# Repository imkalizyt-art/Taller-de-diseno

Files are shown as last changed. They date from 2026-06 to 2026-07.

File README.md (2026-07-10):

# Taller-de-diseno

Sistema IoT que monitorea la humedad del suelo y alerta a un jardinero mediante Telegram. Las mediciones se envían a un dashboard web personalizado alojado en Railway y se almacenan en una base de datos PostgreSQL de Aiven. El sistema también utiliza OpenWeatherMap para consultar el pronóstico de lluvia y mantiene ThingSpeak como respaldo del historial.

**Integrantes:** Enzo Quiñones, Agustín Lastra, Matías Pineda, Carlos León  
**Ramo:** Taller de Diseño en Ingeniería — TEI 201  
**Profesor:** Sebastián Duarte  

## ¿Qué hace el sistema?

**Problema que resuelve:** permite conocer la humedad real del suelo y entregar información útil para decidir cuándo regar, evitando depender solamente de la observación visual o de horarios fijos.

1. El sensor capacitivo mide la humedad del suelo cada 30 segundos.
2. El ESP8266 convierte la lectura ADC en un porcentaje de humedad.
3. Si la humedad cae bajo el 35 %, el suelo se considera seco.
4. Cada medición se envía al dashboard personalizado mediante una API alojada en Railway.
5. Railway guarda los datos en una base PostgreSQL de Aiven para mantener un historial.
6. El dashboard muestra la humedad actual, el valor ADC, el estado del suelo, estadísticas y un gráfico histórico.
7. Cuando el suelo está seco, el ESP8266 envía una alerta por Telegram al jardinero.
8. El mensaje incluye el porcentaje de humedad, el valor ADC, la hora, la temperatura, el pronóstico de lluvia y un enlace al dashboard.
9. Si el suelo continúa seco, se envía un recordatorio cada 10 minutos.
10. Cuando el suelo vuelve a estar húmedo, se envía una confirmación por Telegram.
11. ThingSpeak se mantiene como respaldo secundario de las mediciones.

## Hardware utilizado

| Componente | Modelo |
|---|---|
| Microcontrolador | ESP8266 NodeMCU V3 (ESP-12E, CP2102) |
| Sensor de humedad | Capacitive Soil Moisture Sensor V1.2 |
| Módulo de carga | TP4056 con protección |
| Batería | Li-Po 3.7 V, 2000 mAh |
| Panel solar | 6 V, 1 W |
| Placa de pruebas | Protoboard |
| Indicador | LED conectado al pin D5 |

## Software y plataformas

| Herramienta | Uso |
|---|---|
| Arduino IDE | Desarrollo y carga del firmware |
| Railway | Hosting del backend y del dashboard personalizado |
| Aiven PostgreSQL | Almacenamiento persistente de las mediciones |
| Flask | Backend y API del dashboard |
| Chart.js | Gráfico histórico de humedad |
| Telegram Bot API | Envío de alertas al jardinero |
| OpenWeatherMap API | Pronóstico de lluvia |
| ThingSpeak | Respaldo secundario del historial |
| NTP | Fecha y hora utilizadas por el sistema |

Librerías principales del firmware: `ESP8266WiFi`, `ESP8266HTTPClient`, `WiFiClientSecure`, `ThingSpeak`, `UniversalTelegramBot`, `ArduinoJson` y `NTPClient`.

Dependencias principales del dashboard: `Flask`, `gunicorn` y `psycopg`.

## Estructura del repositorio

```text
Taller-de-diseno/
├── dashboard/          # Página web, API y conexión con Aiven
├── firmware/           # Código fuente del ESP8266
├── hardware/           # Esquema de conexiones y lista de componentes
├── diseno-3d/          # Archivos de Fusion 360, planos y renders
├── docs/               # Documentación y evidencias
├── testing/            # Resultados y protocolo de pruebas
├── FUENTES.md          # Librerías, fuentes externas e IA utilizadas
└── README.md           # Descripción e instrucciones del proyecto
```

## Cómo configurar el proyecto

### 1. Instalar librerías en Arduino IDE

Ir a **Herramientas → Administrar bibliotecas** e instalar:

- `ThingSpeak` de MathWorks.
- `UniversalTelegramBot` de Brian Lough.
- `ArduinoJson` de Benoit Blanchon.
- `NTPClient` de Fabrice Weinberg.

Las librerías `ESP8266WiFi`, `ESP8266HTTPClient` y `WiFiClientSecure` se incluyen con el paquete de placas ESP8266.

### 2. Configurar credenciales en el firmware

En el archivo del firmware deben completarse las siguientes variables:

```cpp
const char* WIFI_SSID = "TU_RED_WIFI";
const char* WIFI_PASSWORD = "TU_CONTRASENA_WIFI";

const char* TELEGRAM_TOKEN = "TU_TOKEN_TELEGRAM";
const char* TELEGRAM_CHAT_ID = "TU_CHAT_ID";

unsigned long TS_CHANNEL_ID = TU_CHANNEL_ID;
const char* TS_WRITE_KEY = "TU_API_KEY_THINGSPEAK";

const char* OWM_API_KEY = "TU_API_KEY_OPENWEATHERMAP";

const char* DEVICE_API_KEY = "TU_DEVICE_API_KEY_DE_RAILWAY";
```

La clave `DEVICE_API_KEY` debe ser exactamente igual a la variable configurada en Railway. Las credenciales reales no deben subirse al repositorio público.

El firmware envía las mediciones a:

```text
https://taller-de-diseno-production.up.railway.app/api/mediciones
```

### 3. Configurar el dashboard

El dashboard se encuentra en la carpeta `dashboard/`.

En Railway se deben configurar estas variables:

```text
DATABASE_URL
DEVICE_API_KEY
HUMIDITY_THRESHOLD=35
ONLINE_WINDOW_MINUTES=15
```

- `DATABASE_URL` corresponde a la URI privada entregada por Aiven.
- `DEVICE_API_KEY` debe coincidir con la clave escrita en el firmware.
- El directorio raíz del servicio en Railway debe ser `/dashboard`.

Dashboard público:

**https://taller-de-diseno-production.up.railway.app**

### 4. Cargar el firmware

1. Conectar el NodeMCU V3 mediante USB.
2. Seleccionar la placa **NodeMCU 1.0 (ESP-12E Module)**.
3. Seleccionar el puerto correspondiente al conversor CP2102.
4. Verificar y cargar el código.
5. Abrir el Monitor Serial a 115200 baudios.
6. Comprobar que aparezcan las lecturas del sensor y el mensaje de envío correcto al dashboard.
7. Abrir el dashboard y verificar que la medición nueva aparezca en la página.

## Calibración del sensor

El sensor capacitivo entrega una lectura inversa a la humedad:

- Un valor ADC mayor representa un suelo más seco.
- Un valor ADC menor representa un suelo más húmedo.

La configuración actual es:

```cpp
const int SENSOR_SECO = 850;
const int SENSOR_AGUA = 380;
const int UMBRAL_RIEGO = 35;
```

La conversión se realiza mediante interpolación lineal:

- `SENSOR_SECO = 850` corresponde a 0 % de humedad.
- `SENSOR_AGUA = 380` corresponde a 100 % de humedad.
- Bajo 35 %, el sistema considera que el suelo necesita riego.

Para recalibrar el sensor se debe medir el valor ADC al aire y luego con la zona sensible en agua, reemplazando los valores anteriores por los resultados obtenidos.

## Dashboard personalizado

El dashboard fue desarrollado por el equipo y es la interfaz principal del sistema:

**https://taller-de-diseno-production.up.railway.app**

La página muestra:

- Humedad actual del suelo.
- Valor ADC.
- Estado seco o humedad adecuada.
- Recomendación de riego.
- Fecha y hora de la última medición.
- Promedio, mínimo y máximo de las últimas 24 horas.
- Cantidad de mediciones registradas.
- Gráfico histórico de humedad.
- Línea de referencia del umbral del 35 %.
- Estado de conexión del ESP8266.

El flujo principal de datos es:

```text
Sensor capacitivo → ESP8266 → API en Railway → PostgreSQL en Aiven → Dashboard personalizado
```

ThingSpeak no se utiliza como dashboard principal; se conserva únicamente como respaldo secundario del historial.

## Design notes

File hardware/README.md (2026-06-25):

# Lista de Materiales y Costos — Hardware

**Proyecto:** Sistema IoT de Monitoreo de Humedad del Suelo  
**Ramo:** TEI 201 — Taller de Diseño en Ingeniería  
**Integrantes:** Enzo Quiñones, Agustín Lastra, Matías Pineda, Carlos León

---

## Lista de Componentes

| N° | Componente | Modelo / Especificación | Cantidad | Precio unit. (CLP) | Total (CLP) | Fuente de referencia |
| 1 | Microcontrolador WiFi | ESP8266 NodeMCU V3 (ESP-12E, CP2102) | 1 | $5.090 | $5.090 | mechatronicstore.cl |
| 2 | Sensor de humedad del suelo | Capacitive Soil Moisture Sensor V1.2 | 1 | $2.990 | $2.990 | maxelectronica.cl |
| 3 | Módulo elevador de voltaje | XL6009 DC-DC Step-Up Boost Converter | 1 | $2.490 | $2.490 | maxelectronica.cl |
| 4 | Módulo cargador de batería | TP4056 con protección integrada (USB-C) | 1 | $2.490 | $2.490 | maxelectronica.cl |
| 5 | Batería recargable | Li-Po 3.7V 2000mAh modelo 103450 | 1 | $5.990 | $5.990 | makerschile.cl (ref.) |
| 6 | Panel solar | 6V 1W (policristalino) | 1 | $3.490 | $3.490 | mechatronicstore.cl (ref.) |
| 7 | Placa de pruebas | Protoboard 830 puntos | 1 | $2.490 | $2.490 | maxelectronica.cl |
| 8 | Cables de conexión | Jumper macho-macho / macho-hembra (x40) | 1 pack | $1.990 | $1.990 | mechatronicstore.cl |

**Costo total del prototipo: $27.020 CLP**

## Justificación de Componentes

### 1. ESP8266 NodeMCU V3 (ESP-12E, CP2102)

El ESP8266 fue elegido como cerebro del sistema por tres razones principales:

- **WiFi integrado:** a diferencia de un Arduino UNO que requeriría un módulo WiFi externo adicional, el ESP8266 integra conectividad WiFi 802.11 b/g/n en el mismo chip, reduciendo componentes y costos.
- **Suficiente capacidad para el proyecto:** con 80 MHz de procesador, 4 MB de memoria flash y 1 pin ADC de 10 bits (0–1023), cubre exactamente las necesidades del sistema: leer el sensor analógico, hacer solicitudes HTTP a OpenWeatherMap y ThingSpeak, y enviar mensajes por Telegram.
- **Compatibilidad directa:** el sensor capacitivo V1.2 opera a 3.3V–5V, compatible con los GPIOs del NodeMCU sin necesidad de adaptadores de nivel.

### 2. Capacitive Soil Moisture Sensor V1.2

El sensor capacitivo fue elegido por sobre el sensor resistivo (tipo FC-28) por razones técnicas y de durabilidad:

- **Principio capacitivo vs. resistivo:** el sensor resistivo hace pasar corriente por el suelo entre dos electrodos metálicos, lo que provoca electrólisis y corrosión en pocas semanas. El sensor capacitivo mide el cambio en la constante dieléctrica del suelo sin contacto eléctrico directo, eliminando este problema.
- **Mayor vida útil:** el fabricante especifica una vida útil mínima de 3 años, adecuada para un sistema de monitoreo permanente en jardín.
- **Salida analógica directa:** entrega una señal analógica de 0–3V proporcional a la humedad, compatible con el único pin ADC del ESP8266 (A0). No requiere conversión adicional.
- **Recubrimiento anticorrosión:** el electrodo tiene una capa protectora que lo hace apto para estar enterrado permanentemente en tierra húmeda.
- **Compatibilidad de voltaje:** opera entre 3.3V y 5.5V, compatible directamente con la salida del ESP8266.

---

### 3. XL6009 DC-DC Step-Up Boost Converter

El módulo XL6009 se incorporó para resolver un problema de voltaje en el sistema de alimentación:

- **Problema:** la batería Li-Po entrega 3.7V nominales (3.2V–4.2V según su estado de carga). El ESP8266 requiere 5V en su pin VIN para operar correctamente a través de su regulador interno de 3.3V.
- **Solución:** el XL6009 eleva el voltaje de la batería (3.2V–4.2V) a un voltaje de salida estable de 5V, garantizando operación continua del ESP8266 independientemente del nivel de carga de la batería.
- **Por qué XL6009 y no LM2596:** el LM2596 es un convertidor reductor (buck), no elevador. El XL6009 es específicamente un elevador de voltaje (boost), necesario para subir de 3.7V a 5V.
- **Eficiencia:** con una eficiencia de conversión de hasta 94%, minimiza las pérdidas energéticas, lo cual es importante para prolongar la autonomía con batería solar.

---

### 4. TP4056 con Protección Integrada

El módulo TP4056 gestiona la carga segura de la batería Li-Po desde el panel solar:

- **Protección contra sobrecargas:** el chip TP4056 controla el proceso de carga mediante el método CC/CV (corriente constante / voltaje constante), cortando la carga cuando la batería alcanza 4.2V para prevenir daños.
- **Protección integrada:** se eligió la versión con DW01A + FS8205A (protección adicional), que añade protección contra sobredescarga, sobrecorriente y cortocircuito — esencial para un sistema autónomo sin supervisión constante.
- **Por qué no conectar el panel solar directo a la batería:** un panel solar sin regulación puede sobrecargar la batería Li-Po con voltajes superiores a 4.2V, lo que genera riesgo de hinchamiento, daño permanente o incendio.
- **Compatibilidad:** acepta entrada de 4.5V–5.5V, compatible con el panel solar de 6V (que en condiciones normales entrega ~5V bajo carga).

---

### 5. Batería Li-Po 3.7V 2000mAh (modelo 103450)

- **Capacidad elegida:** 2000mAh permite autonomía estimada de 8–12 horas de operación continua del sistema, suficiente para días con poca luz solar (nublado) donde el panel no recarga completamente.
- **Química Li-Po vs. alcalina:** las baterías alcalinas (AA/AAA) no son recargables por panel solar. El Li-Po permite ciclos continuos de carga/descarga sin efecto memoria y entrega alta densidad de energía en formato compacto.
- **Voltaje nominal 3.7V:** compatible con el módulo TP4056 (diseñado para celdas Li-Po de una celda a 3.7V) y con el XL6009 (rango de entrada mínimo 3.5V).
- **Formato físico:** el modelo 103450 (10mm × 34mm × 50mm) es compacto y fácil de integrar en el protoboard o carcasa del prototipo.

---

### 6. Panel Solar 6V 1W

- **Fuente de energía renovable:** permite que el sistema opere de forma autónoma en un jardín sin acceso a red eléctrica, cumpliendo con el requisito de instalación permanente.
- **Potencia elegida (1W / ~166mA a 6V):** el ESP8266 consume aproximadamente 80mA en operación WiFi. Con 5–6 horas de sol útil diario, el panel entrega energía suficiente para recargar la batería y compensar el consumo del sistema.
- **Voltaje de 6V:** entrega ~5V bajo carga, compatible con el rango de entrada del TP4056 (4.5V–5.5V). No se conecta directamente a la batería — siempre pasa por el TP4056.
- **Formato pequeño:** un panel de 1W es compacto y discreto para instalación en jardín, sin requerir estructura de soporte especial.

---

### 7. Protoboard 830 puntos

- **Prototipado sin soldadura:** permite modificar el circuito rápidamente durante el desarrollo, depuración y ajuste de parámetros (pines, resistencias, reordenamiento de componentes) sin necesidad de herramientas de soldadura.
- **Capacidad suficiente:** 830 puntos es el estándar para proyectos de complejidad media; permite ubicar el NodeMCU, el TP4056, el XL6009 y los cables del sensor con espacio disponible.
- **Etapa de prototipo:** para una versión final de producción, el circuito sería transferido a una PCB, pero en etapa de prototipo universitario la protoboard es la solución estándar.

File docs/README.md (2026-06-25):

# Manual de Uso — Sistema de Riego Inteligente IoT

**Proyecto:** Sistema IoT de monitoreo de humedad del suelo  
**Ramo:** TEI 201 — Taller de Diseño en Ingeniería  
**Integrantes:** Enzo Quiñones, Agustín Lastra, Matías Pineda, Carlos León

## 1. Descripción general

El sistema monitorea la humedad del suelo de forma autónoma mediante conexion a wifi, notifica al jardinero por Telegram cuando el suelo necesita riego. Funciona con batería recargable y panel solar, por lo que no requiere conexión a la red eléctrica.

## 2. Componentes del sistema

 Componente  Función 

- ESP8266 NodeMCU V3  Cerebro del sistema: lee el sensor, procesa datos y envía alertas 
- Sensor Capacitivo V1.2  Mide la humedad del suelo 
- Batería Li-Po 3.7V 2000mAh  Alimentación del sistema 
- Panel solar 6V 1W  Recarga la batería durante el día 
- Módulo TP4056  Controla la carga de la batería de forma segura 

## 3. Encendido del sistema

1. Asegurarse de que la batería esté cargada (el LED del TP4056 debe estar azul o verde)
2. Conectar la batería al módulo TP4056
3. El ESP8266 enciende automáticamente y se conecta al WiFi configurado
4. Esperar aproximadamente **10–15 segundos** para que establezca conexión
5. El sistema comienza a medir y enviar datos a ThingSpeak de inmediato

## 4. Mensajes de Telegram

El sistema envía tres tipos de mensajes automáticos:

### Alerta de suelo seco
- Se envía cuando la humedad baja del 35%.

🚨 ALERTA: Suelo seco detectado

- 💧 Humedad: 22%
- Valor ADC: 714
- 🕐 Hora: 14:32:05 UTC
- 🌧️ Pronóstico lluvia próximos 5 días: No se esperan lluvias
- ✅ Recomendación: Regar hoy
- Ver historial: https://thingspeak.mathworks.com/channels/3416600
###  Recordatorio periódico
- Si el suelo sigue seco después de 10 minutos, se envía un recordatorio con los datos actualizados.
### 🟢 Confirmación de suelo húmedo
Se envía automáticamente cuando la humedad vuelve a superar el 35% tras haber estado seca.
- Suelo húmedo — No se requiere riego

💧 Humedad actual: 61%
🕐 Hora: 15:10:22 UTC

## 5. Ver el historial de datos

1. Abrir el navegador e ir a:  
   👉 https://thingspeak.mathworks.com/channels/3416600
2. El dashboard muestra tres gráficos en tiempo real:
   - **Field 1:** Valor ADC crudo del sensor
   - **Field 2:** Porcentaje de humedad calculado
   - **Field 3:** Estado de alerta (0 = húmedo, 1 = seco)
3. Es posible filtrar por rango de fechas usando los controles del canal

---

## 6. Interpretación de la humedad

 Rango  Estado, Acción recomendada 

 - **0% – 35%**    Suelo seco  Regar — el sistema ya habrá alertado 
-  **35% – 60%**   Humedad moderada  Monitorear 
- **60% – 100%**   Suelo húmedo  No requiere riego 

## 7. Mantenimiento

### Revisión semanal
- Verificar que el panel solar esté expuesto al sol sin obstrucciones
- Revisar que el sensor esté correctamente insertado en el suelo (hasta la línea marcada, sin sumergir la electrónica)
- Confirmar que la conexion desde el dispostivo al celular esten funcionando de manera correcta

### Revisión mensual
- Revisar conexiones en el protoboard
- Verificar nivel de carga de la batería
- Limpiar el sensor o la parte que cubre el sensor con paño húmedo si hay acumulación de tierra

### Recalibración del sensor
Si las lecturas de humedad parecen incorrectas:
1. Medir el valor ADC con el sensor en aire → actualizar SENSOR_SECO
2. Medir el valor ADC con el sensor en agua → actualizar SENSOR_AGUA
3. Cargar el firmware actualizado al ESP8266

## 8. Solución de problemas

Síntoma  Causa probable  Solución 

- No llegan mensajes a Telegram  Sin conexión WiFi  
- Humedad siempre en 0% o 100%  Sensor descalibrado  Recalibrar con mediciones reales 
- El sistema no enciende  Batería descargada  Conectar al cargador o esperar carga solar 
- Mensajes repetidos muy seguidos  Bug en anti-spam  Revisar valor de millis() en el código 

## 9. Apagar el sistema

Desconectar la batería del módulo TP4056. El sistema no tiene interruptor físico; simplemente se desconecta la alimentación.

## 10. Contacto del equipo

Para dudas sobre el sistema, contactar a cualquier integrante del equipo a través del curso TEI 201.

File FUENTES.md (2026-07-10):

# FUENTES DEL PROYECTO

Este archivo registra las librerías, servicios, códigos externos adaptados y herramientas de inteligencia artificial utilizadas en el desarrollo del sistema de monitoreo de humedad del suelo.

---

## 1. Librerías utilizadas

| Librería, dependencia o servicio | Versión | Enlace oficial | Uso en el proyecto |
|---|---:|---|---|
| ESP8266 Arduino Core (`ESP8266WiFi`, `ESP8266HTTPClient`, `WiFiClient`, `WiFiClientSecure` y `WiFiUDP`) | 3.1.2 | https://github.com/esp8266/Arduino | Conexión Wi-Fi del NodeMCU, solicitudes HTTP/HTTPS, comunicación con el dashboard y conexión NTP |
| ThingSpeak | 2.0.0 | https://github.com/mathworks/thingspeak-arduino | Respaldo secundario de las mediciones de humedad, estado del suelo y lluvia pronosticada |
| UniversalTelegramBot | 1.3.0 | https://github.com/witnessmenow/Universal-Arduino-Telegram-Bot | Envío de alertas, recordatorios y confirmaciones de riego por Telegram |
| ArduinoJson | 6.21.5 | https://arduinojson.org | Lectura de respuestas de OpenWeatherMap y creación del JSON enviado a Railway |
| NTPClient | 3.2.1 | https://github.com/arduino-libraries/NTPClient | Obtención de fecha y hora para los mensajes del sistema |
| Flask | `>=3.0,<4` | https://flask.palletsprojects.com | Backend del dashboard, recepción de mediciones y creación de las rutas de la API |
| Psycopg | `>=3.1,<4` | https://www.psycopg.org/psycopg3/docs/ | Conexión entre la aplicación Flask y PostgreSQL de Aiven |
| Gunicorn | `>=22,<24` | https://gunicorn.org | Ejecución del backend Flask en Railway |
| Chart.js | 4.4.7 | https://www.chartjs.org/docs/latest/ | Gráfico histórico de humedad y línea del umbral de riego |
| Railway | Servicio web | https://docs.railway.com | Hosting del backend y del dashboard personalizado |
| Aiven for PostgreSQL | PostgreSQL 17 | https://aiven.io/docs/products/postgresql | Almacenamiento persistente del historial de mediciones |
| OpenWeatherMap | 5 Day / 3 Hour Forecast API | https://openweathermap.org/forecast5 | Consulta de temperatura y lluvia pronosticada |

---

## 2. Código externo adaptado

### Conexión Wi-Fi y solicitudes de red

- **Fuente:** documentación oficial de ESP8266 Arduino Core.  
  https://arduino-esp8266.readthedocs.io/en/latest/esp8266wifi/readme.html
- **Adaptación realizada:** se incorporó la conexión del NodeMCU a la red Wi-Fi, control del estado de conexión y uso de clientes HTTP y HTTPS para comunicarse con ThingSpeak, Telegram, OpenWeatherMap y Railway.

### Lectura y calibración del sensor capacitivo

- **Fuente:** documentación del Capacitive Soil Moisture Sensor V1.2.  
  https://www.sigmaelectronica.net/manuals/SMTMS-2-4.pdf
- **Adaptación realizada:** la lectura ADC se transforma en porcentaje mediante interpolación lineal entre `SENSOR_SECO = 850` y `SENSOR_AGUA = 380`. El umbral de riego se fijó en 35 % según las pruebas realizadas con el sensor.

### Envío de datos a ThingSpeak

- **Fuente:** documentación oficial de ThingSpeak para Arduino.  
  https://www.mathworks.com/help/thingspeak/use-arduino-client-to-write-to-channel.html
- **Adaptación realizada:** se configuró el envío de humedad, estado del suelo y lluvia pronosticada. ThingSpeak se conserva como respaldo secundario y ya no corresponde al dashboard principal del proyecto.

### Alertas mediante Telegram y consulta del clima

- **Fuentes:** ejemplos de UniversalTelegramBot y documentación de OpenWeatherMap.  
  https://github.com/witnessmenow/Universal-Arduino-Telegram-Bot/tree/master/examples  
  https://openweathermap.org/forecast5
- **Adaptación realizada:** se implementaron alertas de suelo seco, recordatorios cada 10 minutos y confirmación cuando el suelo vuelve a estar húmedo. Los mensajes incluyen humedad, lectura ADC, hora, temperatura, pronóstico de lluvia, recomendación y enlace al dashboard personalizado.

### Dashboard personalizado, API y base de datos

- **Fuentes:** documentación oficial de Flask, Psycopg, Chart.js, Railway y Aiven.  
  https://flask.palletsprojects.com  
  https://www.psycopg.org/psycopg3/docs/  
  https://www.chartjs.org/docs/latest/  
  https://docs.railway.com  
  https://aiven.io/docs/products/postgresql
- **Adaptación realizada:** se creó una página propia para mostrar humedad actual, ADC, estado del suelo, recomendación, última actualización, promedio, mínimo, máximo y gráfico histórico. Flask recibe las mediciones del ESP8266, valida la clave `DEVICE_API_KEY` y las almacena en PostgreSQL de Aiven. La aplicación se encuentra desplegada en Railway.

### Integración del ESP8266 con el dashboard

- **Fuente:** documentación de `ESP8266HTTPClient`, `WiFiClientSecure` y ArduinoJson.
- **Adaptación realizada:** se agregó al firmware la función `enviarADashboard()`, que crea un objeto JSON con humedad, ADC, estado seco/húmedo, temperatura, lluvia y nombre del dispositivo. Luego envía una solicitud HTTPS `POST` a la API de Railway utilizando el encabezado privado `X-API-Key`.
- **Estado de validación:** el código fue integrado al firmware. El envío desde el dispositivo debe verificarse nuevamente al cargar la versión final en el ESP8266.

---

## 3. Uso de Inteligencia Artificial

### Diseño inicial y desarrollo del firmware

- **Herramienta:** Claude, de Anthropic.
- **Fecha:** junio de 2026.
- **Prompt utilizado:** se solicitó plantear y explicar un sistema de monitoreo de humedad con ESP8266, sensor capacitivo, ThingSpeak, Telegram, NTP y OpenWeatherMap.
- **Uso:** apoyo en la arquitectura inicial, migración a ESP8266, generación y depuración del firmware, mensajes de Telegram y control anti-spam con `millis()`.
- **Adaptación:** el equipo configuró el hardware real, las credenciales, la ubicación de OpenWeatherMap, los tiempos de medición, los valores de calibración y el umbral de 35 %.
- **Comprensión:** el equipo comprende la lectura ADC, la conversión a porcentaje, el control del LED, la lógica de alertas y la consulta del clima.

### Desarrollo del dashboard personalizado

- **Herramienta:** ChatGPT, de OpenAI.
- **Fecha:** julio de 2026.
- **Prompt utilizado:** “Crear una página web propia como dashboard para el sistema de humedad, alojarla en Railway y guardar las mediciones en PostgreSQL de Aiven, sin depender de los gráficos genéricos de ThingSpeak”.
- **Uso:** generación de la estructura inicial de `app.py`, HTML, CSS, JavaScript, conexión con PostgreSQL, rutas de la API, estadísticas y gráfico histórico.
- **Adaptación:** se utilizaron los datos reales del proyecto: humedad, ADC, estado del suelo, temperatura y lluvia. Se fijó el umbral en 35 %, se configuró el dominio público de Railway y se conectó la base de datos creada por el equipo en Aiven.
- **Comprensión:** el equipo comprende que el ESP8266 envía un JSON por HTTPS, Flask valida la clave, PostgreSQL guarda la medición y la página consulta las rutas de la API para actualizar las tarjetas y el gráfico.

### Integración del firmware y actualización de documentación

- **Herramienta:** ChatGPT, de OpenAI.
- **Fecha:** julio de 2026.
- **Prompts utilizados:** se solicitó integrar el firmware existente con la nueva API sin eliminar las configuraciones originales, y actualizar `README.md` y `FUENTES.md` de acuerdo con la rúbrica.
- **Uso:** incorporación de `enviarADashboard()`, cambio de los enlaces de Telegram al dashboard propio y actualización de la documentación del repositorio.
- **Adaptación:** se mantuvieron la calibración, los pines, los tiempos, Telegram, OpenWeatherMap y ThingSpeak del código base. Solo se agregó la comunicación con Railway/Aiven y se actualizó la documentación para reflejar el sistema actual.
- **Comprensión:** el equipo puede explicar la estructura JSON, el encabezado `X-API-Key`, las rutas de la API, el uso de variables privadas en Railway y la función de Aiven como repositorio persistente.

---

## 4. Hardware utilizado

| Componente | Modelo o especificación | Datasheet o referencia |
|---|---|---|
| Microcontrolador | ESP8266 NodeMCU V3, ESP-12E, CP2102 | https://www.nodemcu.com/index_en.html |
| Sensor de humedad | Capacitive Soil Moisture Sensor V1.2 | https://www.sigmaelectronica.net/manuals/SMTMS-2-4.pdf |
| Módulo de carga | TP4056 con protección | https://dlnmh9ip6v2uc.cloudfront.net/datasheets/Prototyping/TP4056.pdf |
| Batería | Li-Po 3.7 V, 2000 mAh | Componente adquirido por el equipo |
| Panel solar | 6 V, 1 W | Componente adquirido por el equipo |
| Placa de pruebas | Protoboard | Componente utilizado en el montaje |

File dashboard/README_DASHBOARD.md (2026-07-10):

# Dashboard personalizado — Sistema de humedad del suelo

Aplicación web desarrollada por el equipo para visualizar las mediciones
del ESP8266 sin depender del dashboard genérico de ThingSpeak.

## Funciones

- Humedad actual y valor ADC.
- Estado del suelo: seco o humedad adecuada.
- Recomendación de riego.
- Promedio, mínimo y máximo de las últimas 24 horas.
- Gráfico histórico con el umbral de 35%.
- Estado de conexión del dispositivo.
- Persistencia de datos en PostgreSQL de Aiven.
- Actualización automática cada 10 segundos.

## Variables de entorno necesarias en Railway

| Variable | Contenido |
|---|---|
| `DATABASE_URL` | URI completa entregada por Aiven |
| `DEVICE_API_KEY` | Clave privada compartida solo con el ESP8266 |
| `HUMIDITY_THRESHOLD` | `35` |
| `ONLINE_WINDOW_MINUTES` | `15` |

No subir un archivo `.env` ni credenciales reales al repositorio.

## Rutas de la aplicación

- `GET /` — dashboard.
- `GET /health` — comprueba la aplicación y la base de datos.
- `POST /api/mediciones` — recibe datos del ESP8266.
- `GET /api/mediciones?limit=120` — entrega el historial.
- `GET /api/resumen` — entrega la medición actual y estadísticas.

## Formato que envía el ESP8266

Encabezado:

```text
X-API-Key: la-misma-clave-configurada-en-railway
Content-Type: application/json
```

Cuerpo mínimo:

```json
{
  "humedad": 42.5,
  "adc": 638,
  "suelo_seco": false,
  "dispositivo": "ESP8266"
}
```

También acepta, de forma opcional:

```json
{
  "temperatura": 21.4,
  "lluvia_24h": 0.0
}
```

## Prueba manual

Después de desplegar, reemplazar los valores:

```bash
curl -X POST "https://TU-DOMINIO.up.railway.app/api/mediciones" \
  -H "Content-Type: application/json" \
  -H "X-API-Key: TU_CLAVE_PRIVADA" \
  -d '{"humedad":42.5,"adc":638,"suelo_seco":false,"dispositivo":"ESP8266"}'
```

## Configuración de Railway en un repositorio con varias carpetas

Como el repositorio completo contiene firmware, hardware y diseño 3D,
configurar el **Root Directory** del servicio de Railway como:

```text
/dashboard
```

Luego crear un dominio público desde la sección Networking del servicio.

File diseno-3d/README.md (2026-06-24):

# Diseño 3D

En esta carpeta se encuentra:

- Archivos de Fusion 360.
- Planos técnicos.
- Renders exteriores.
- Modelo del encapsulado.

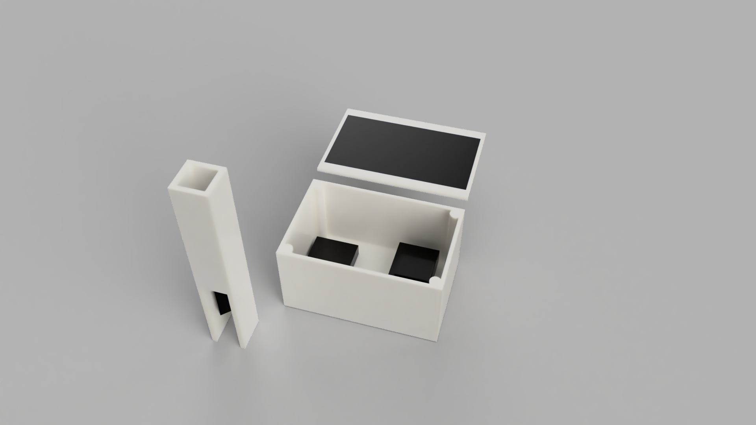
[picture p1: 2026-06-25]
diseno-3d/Render.png

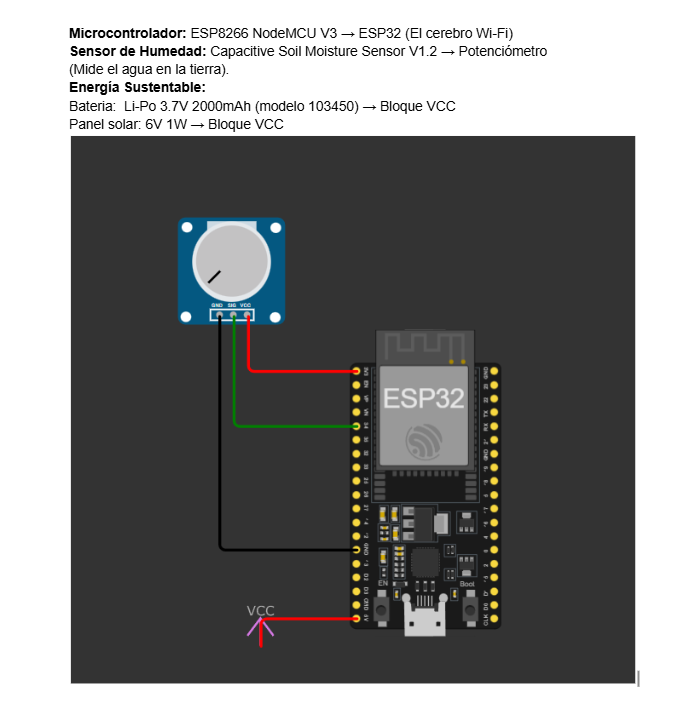
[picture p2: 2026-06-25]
hardware/WOKWI.png

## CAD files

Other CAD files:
diseno-3d/CajaSinTapa.f3d
diseno-3d/EstacaFinal.f3d
diseno-3d/Gemelo 3D.f3z
diseno-3d/TapaPanelSolar.f3d

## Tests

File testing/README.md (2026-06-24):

# Testing y validación

En esta carpeta se guardarán:

* Protocolo de pruebas.
* Datos obtenidos por el sensor.
* Gráficas de humedad.
* Registro de errores y soluciones.
* Resultados de las pruebas en suelo seco y húmedo.

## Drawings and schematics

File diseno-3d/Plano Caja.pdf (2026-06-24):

# PLANO TECNICO - CAJA PORTA-ELECTRONICA

# Proyeccion ortogonal (sistema ISO, primer diedro) -- Escala 1:2 -- Unidades: mm

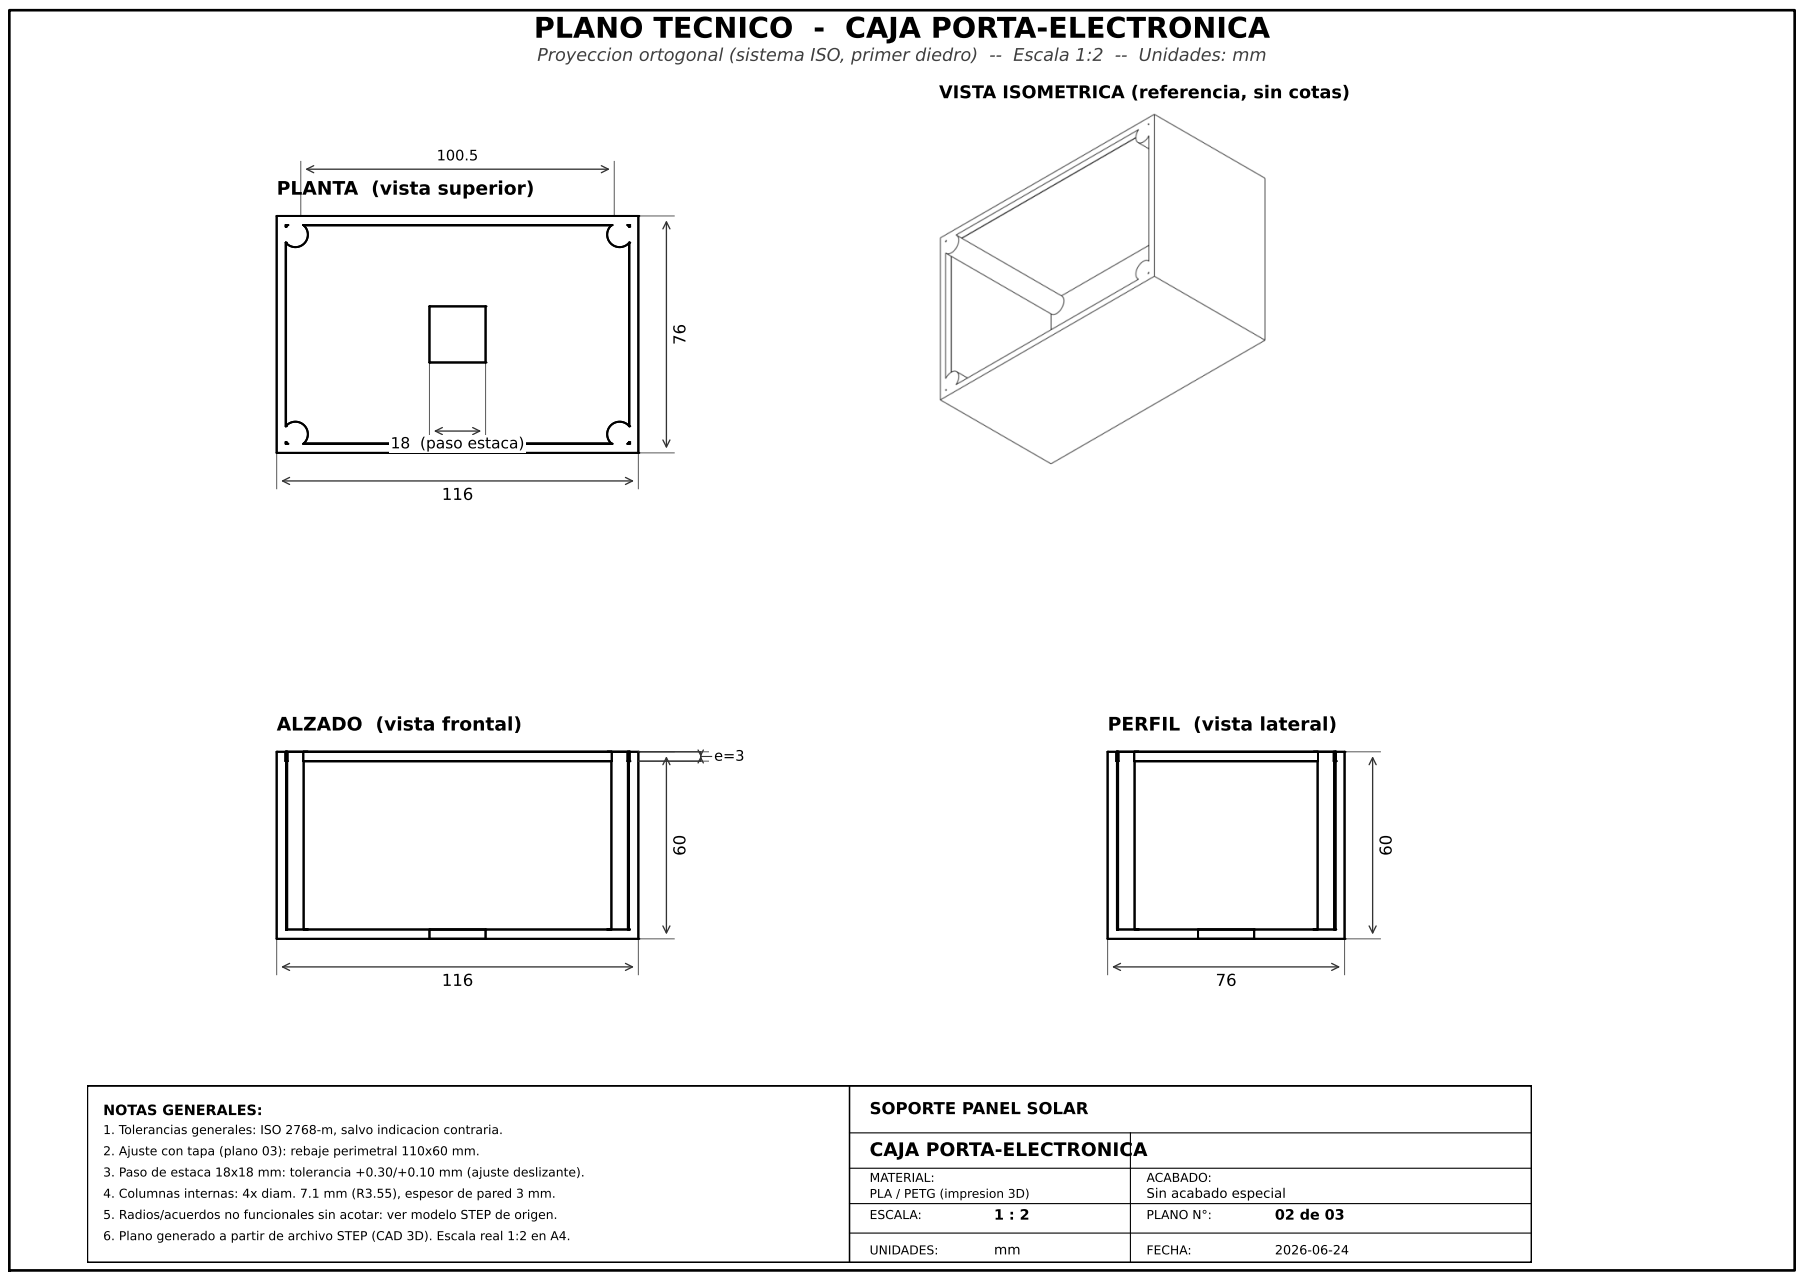
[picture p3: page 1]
18 (paso estaca); ESCALA:; UNIDADES:; PLANO N°:; FECHA:

VISTA ISOMETRICA (referencia, sin cotas)

PLANTA (vista superior)

ALZADO (vista frontal)

PERFIL (vista lateral)

NOTAS GENERALES:
1. Tolerancias generales: ISO 2768-m, salvo indicacion contraria.

SOPORTE PANEL SOLAR

2. Ajuste con tapa (plano 03): rebaje perimetral 110x60 mm.

CAJA PORTA-ELECTRONICA

3. Paso de estaca 18x18 mm: tolerancia +0.30/+0.10 mm (ajuste deslizante).

4. Columnas internas: 4x diam. 7.1 mm (R3.55), espesor de pared 3 mm.

MATERIAL:
PLA / PETG (impresion 3D)

ACABADO:
Sin acabado especial

5. Radios/acuerdos no funcionales sin acotar: ver modelo STEP de origen.

6. Plano generado a partir de archivo STEP (CAD 3D). Escala real 1:2 en A4.

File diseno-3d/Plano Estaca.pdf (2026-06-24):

# PLANO TECNICO - ESTACA / POSTE DE ANCLAJE

# Proyeccion ortogonal (sistema ISO, primer diedro) -- Escala 1:2 -- Unidades: mm

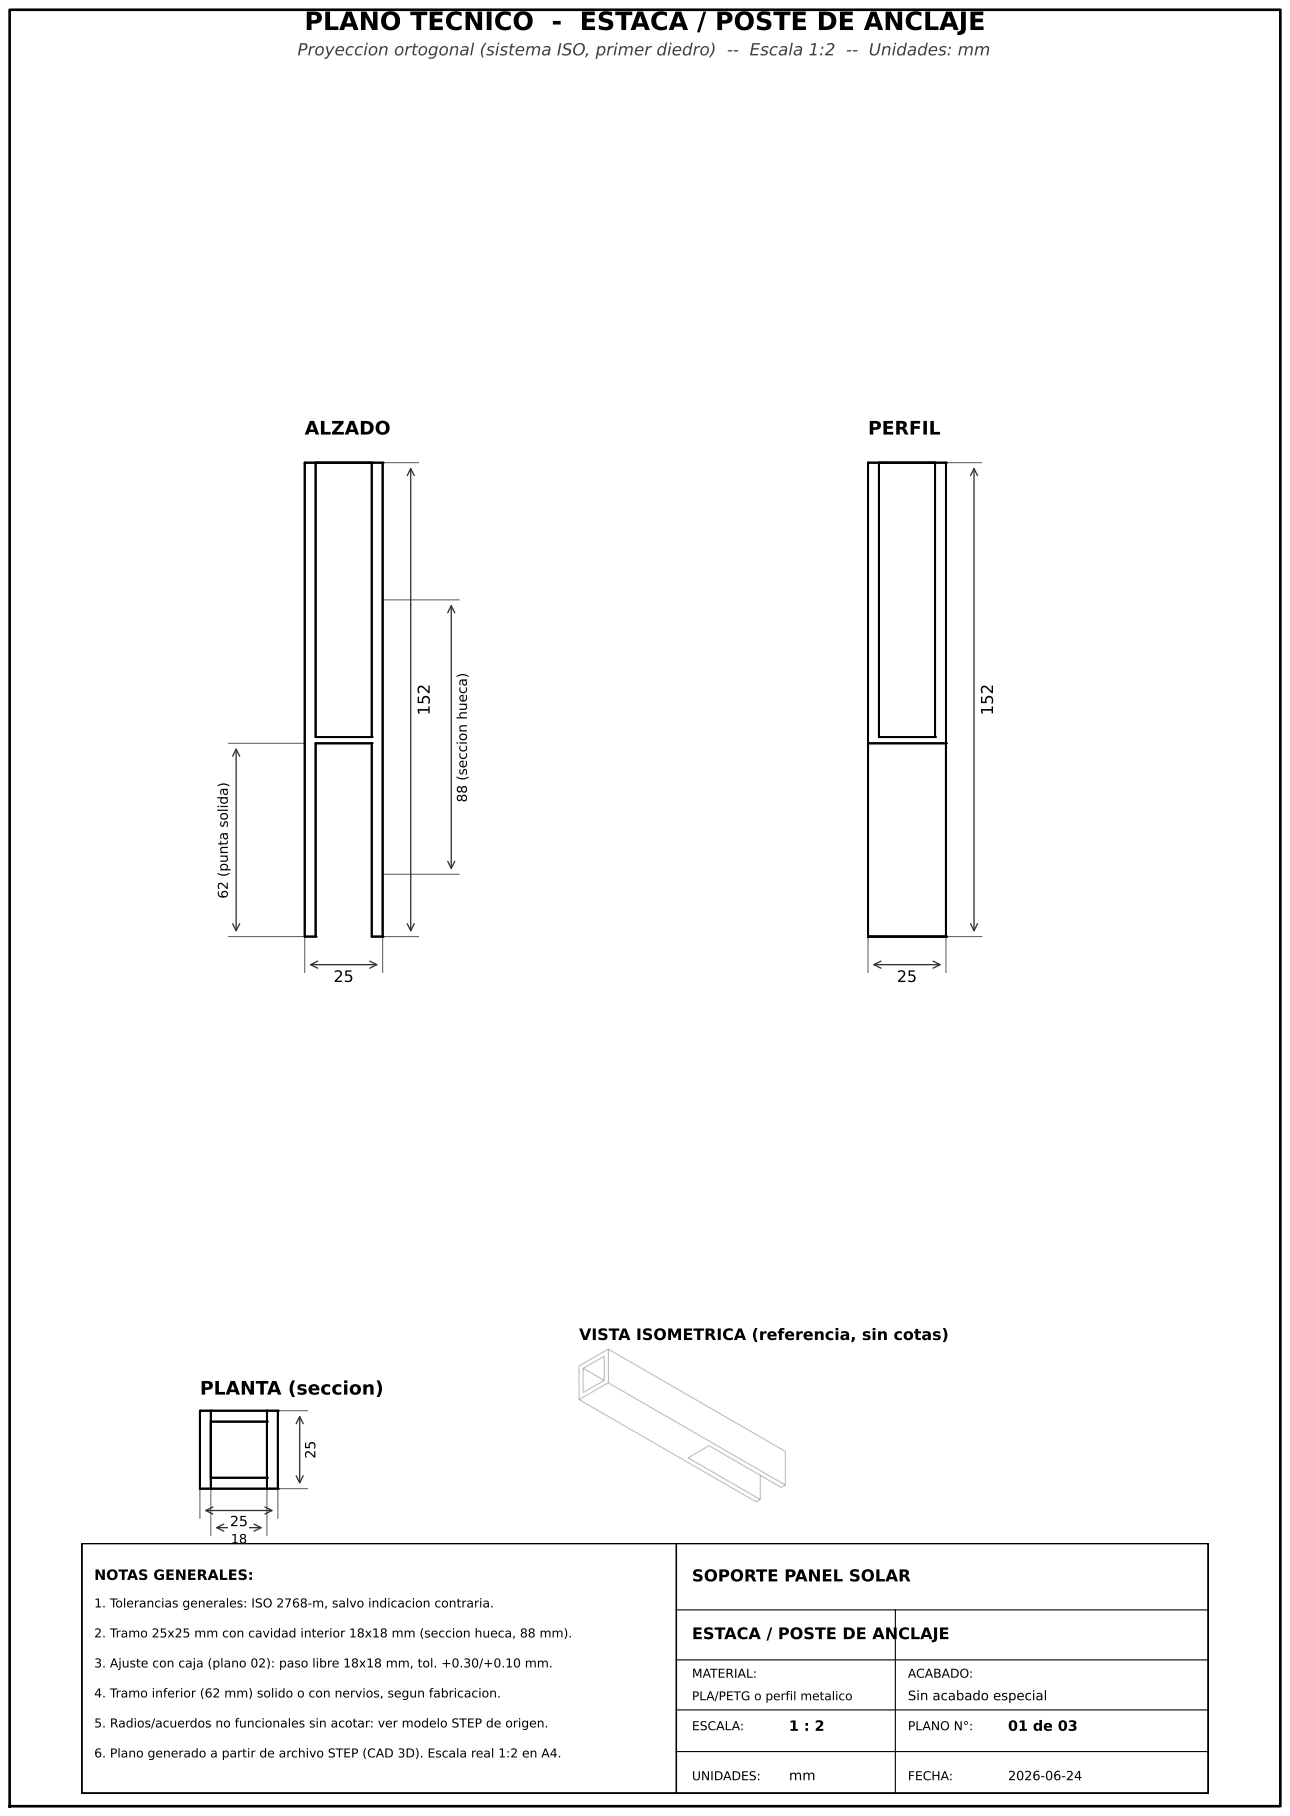
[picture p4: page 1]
ALZADO; 88 (seccion hueca); 62 (punta solida); PERFIL; PLANTA (seccion); NOTAS GENERALES:; MATERIAL:; ESCALA:; UNIDADES:; PLANO N°:; FECHA:

VISTA ISOMETRICA (referencia, sin cotas)

SOPORTE PANEL SOLAR

1. Tolerancias generales: ISO 2768-m, salvo indicacion contraria.

ESTACA / POSTE DE ANCLAJE

2. Tramo 25x25 mm con cavidad interior 18x18 mm (seccion hueca, 88 mm).

3. Ajuste con caja (plano 02): paso libre 18x18 mm, tol. +0.30/+0.10 mm.

ACABADO:
Sin acabado especial

4. Tramo inferior (62 mm) solido o con nervios, segun fabricacion.

PLA/PETG o perfil metalico

5. Radios/acuerdos no funcionales sin acotar: ver modelo STEP de origen.

6. Plano generado a partir de archivo STEP (CAD 3D). Escala real 1:2 en A4.

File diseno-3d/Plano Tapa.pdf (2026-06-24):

# PLANO TECNICO - TAPA PANEL SOLAR

# Proyeccion ortogonal (sistema ISO, primer diedro) -- Escala 1:2 -- Unidades: mm

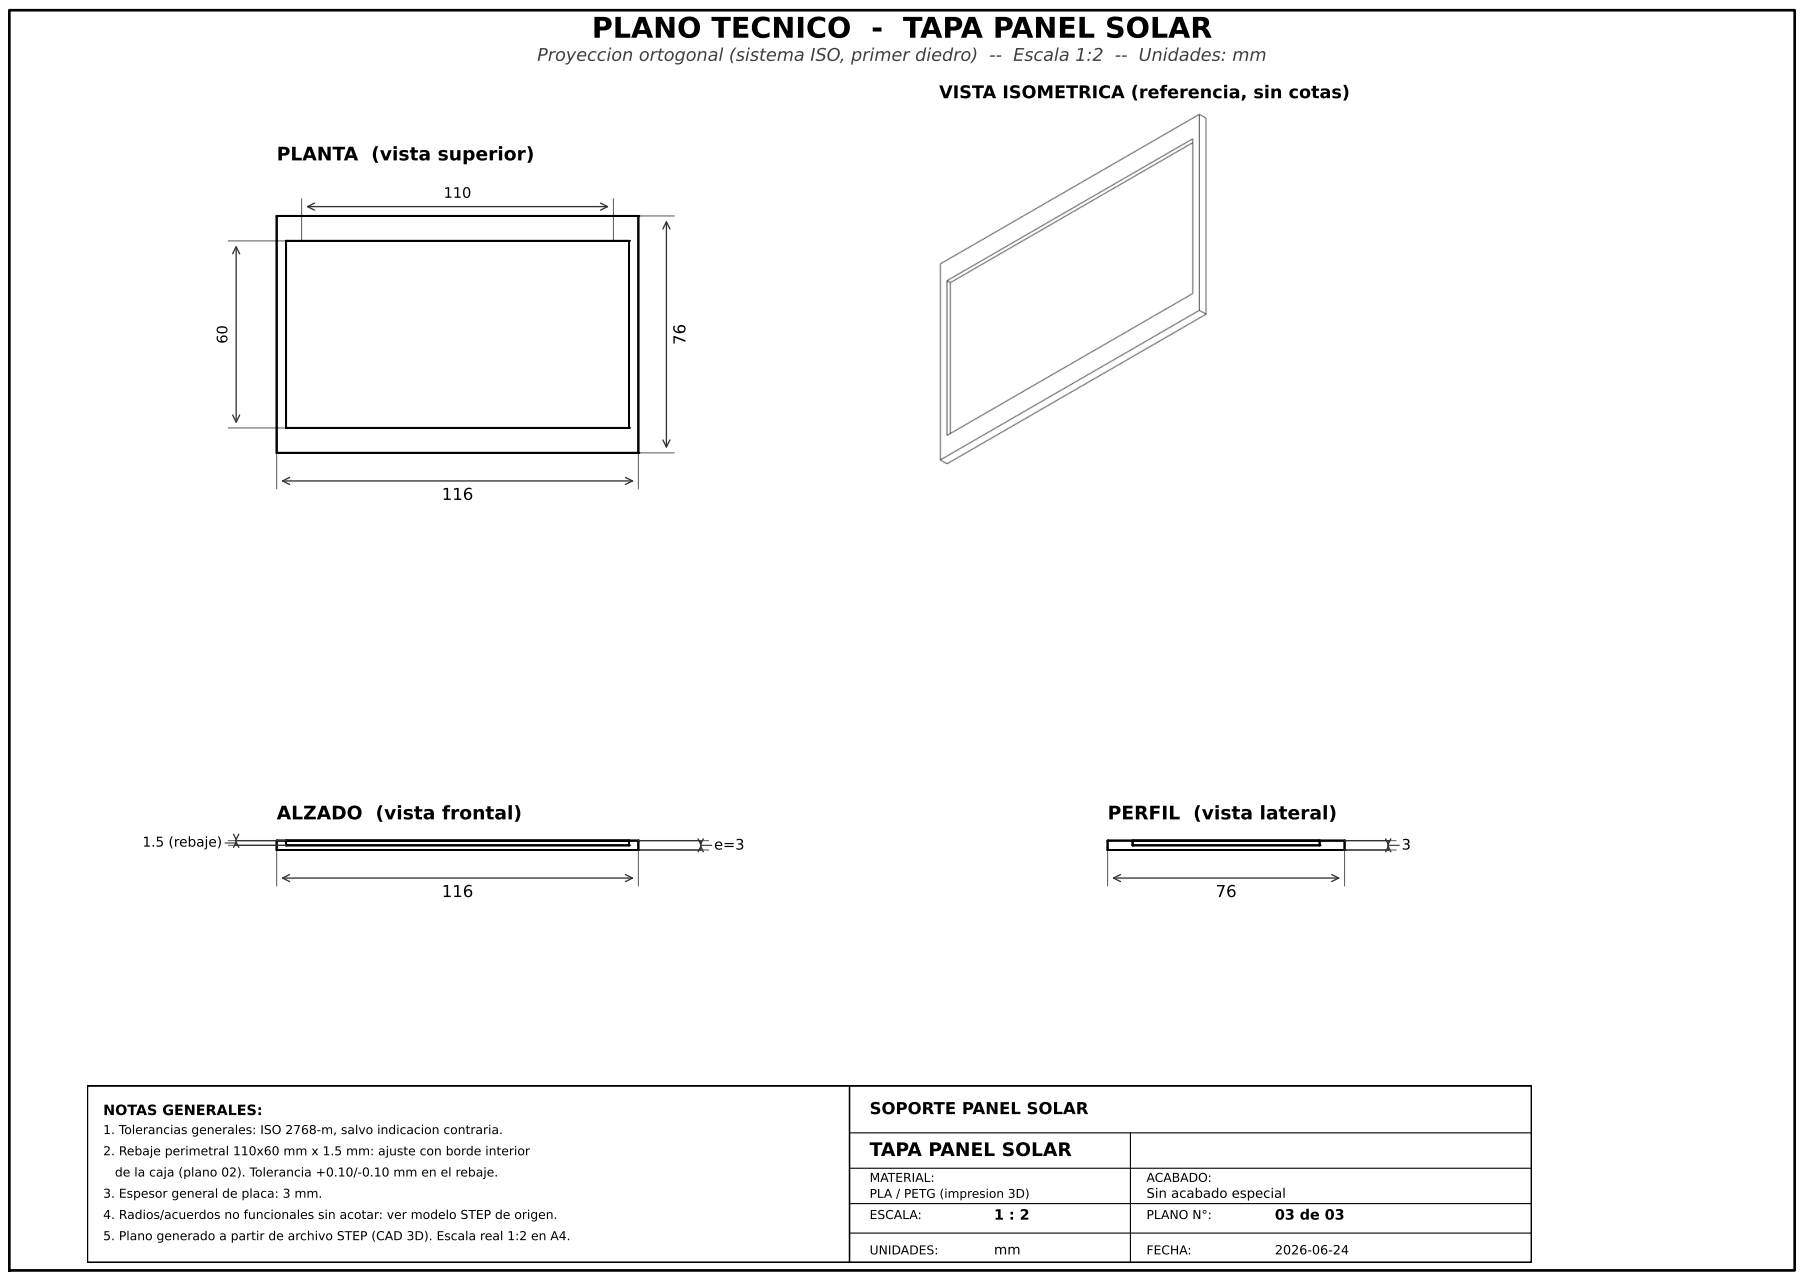
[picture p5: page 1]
1.5 (rebaje); ESCALA:; UNIDADES:; PLANO N°:; FECHA:

VISTA ISOMETRICA (referencia, sin cotas)

PLANTA (vista superior)

ALZADO (vista frontal)

PERFIL (vista lateral)

NOTAS GENERALES:
1. Tolerancias generales: ISO 2768-m, salvo indicacion contraria.

SOPORTE PANEL SOLAR

2. Rebaje perimetral 110x60 mm x 1.5 mm: ajuste con borde interior

TAPA PANEL SOLAR

de la caja (plano 02). Tolerancia +0.10/-0.10 mm en el rebaje.

3. Espesor general de placa: 3 mm.

MATERIAL:
PLA / PETG (impresion 3D)

ACABADO:
Sin acabado especial

4. Radios/acuerdos no funcionales sin acotar: ver modelo STEP de origen.

5. Plano generado a partir de archivo STEP (CAD 3D). Escala real 1:2 en A4.

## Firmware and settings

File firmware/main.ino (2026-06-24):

// ============================================================
//  SISTEMA INTELIGENTE DE RIEGO — TEI201 — AVANCE #3
//  ESP8266 NodeMCU V3 + Sensor Capacitivo V1.2 + Li-Po + Solar
//
//  Ciclo del sistema:
//    Sensor detecta suelo seco
//    → Alerta por Telegram al jardinero (con humedad, hora, clima)
//    → Datos enviados a ThingSpeak (dashboard e historial)
//    → Pronóstico de lluvia para recomendar días de riego
//
//  Hardware:
//    - ESP8266 NodeMCU V3 (ESP-12E, CP2102)
//    - Capacitive Soil Moisture Sensor V1.2
//    - Li-Po 3.7V 2000mAh (103450) + Módulo TP4056
//    - Panel Solar 6V 1W
//
//  Librerías necesarias (instalar desde Arduino IDE):
//    - ThingSpeak by MathWorks       (v2.0.0+)
//    - ArduinoJson by bblanchon      (v6.x)
//    - UniversalTelegramBot by Brian Lough (v1.3.0+)
//    - WiFiClientSecure (incluida en ESP8266 board package)
//    - NTPClient by Fabrice Weinberg (v3.2.1+)
// ============================================================

#include <ESP8266WiFi.h>
#include <ESP8266HTTPClient.h>
#include <WiFiClientSecure.h>
#include <WiFiClient.h>
#include <ArduinoJson.h>
#include <UniversalTelegramBot.h>
#include <NTPClient.h>
#include <WiFiUDP.h>
#include "ThingSpeak.h"

// ── CREDENCIALES WiFi ──────────────────────────────────────
const char* WIFI_SSID     = "TU_RED_WIFI";
const char* WIFI_PASSWORD = "TU_CONTRASEÑA";

// ── TELEGRAM ───────────────────────────────────────────────
// 1. Habla con @BotFather en Telegram → /newbot → copia el token
// 2. Habla con @userinfobot → copia tu chat_id numérico
const char* TELEGRAM_TOKEN   = "XXXXXXXXXX:XXXXXXXXXXXXXXXXXXXXXXXXXXXXXXXXXXX";
const char* TELEGRAM_CHAT_ID = "XXXXXXXXXX";  // ID del jardinero

// ── THINGSPEAK ─────────────────────────────────────────────
// Crea canal en thingspeak.com con 3 fields:
//   Field 1: Humedad suelo (%)
//   Field 2: Estado (0=seco, 1=húmedo)
//   Field 3: Lluvia próximas 24h (mm)
unsigned long TS_CHANNEL_ID = 0000000;          // Tu Channel ID
const char*   TS_WRITE_KEY  = "XXXXXXXXXXXXXXXX"; // Write API Key
// URL pública del canal para incluir en mensajes de Telegram
const char*   TS_CANAL_URL  = "https://thingspeak.com/channels/0000000"; // Reemplaza con tu Channel ID

// ── OPENWEATHERMAP ─────────────────────────────────────────
// Plan gratuito en openweathermap.org/api → "5 Day / 3 Hour Forecast"
const char* OWM_API_KEY = "XXXXXXXXXXXXXXXXXXXXXXXXXXXXXXXX";
const char* OWM_CITY    = "Santiago";
const char* OWM_COUNTRY = "CL";

// ── PINES (ESP8266 NodeMCU V3) ─────────────────────────────
// El NodeMCU solo tiene UN pin analógico: A0
// El sensor capacitivo se conecta directamente a A0
const int PIN_SENSOR = A0;

// Pin digital para LED indicador (opcional, pin D5 = GPIO14)
const int PIN_LED = D5;

// ── CALIBRACIÓN DEL SENSOR CAPACITIVO V1.2 ─────────────────
// IMPORTANTE: Estos valores varían según tu sensor.
// Procedimiento de calibración:
//   1. Con sensor al aire (seco) → anota el valor del Serial Monitor → SENSOR_SECO
//   2. Con sensor en agua       → anota el valor del Serial Monitor → SENSOR_AGUA
// El ESP8266 tiene ADC de 10 bits → rango 0–1023
const int SENSOR_SECO  = 850;   // Valor ADC con sensor al aire
const int SENSOR_AGUA  = 380;   // Valor ADC con sensor en agua
const int UMBRAL_RIEGO = 35;    // % de humedad bajo el cual el suelo se considera seco

// ── TIEMPOS ────────────────────────────────────────────────
const unsigned long INTERVALO_SENSOR = 30000;    // Leer sensor cada 30 seg
const unsigned long INTERVALO_CLIMA  = 3600000;  // Consultar clima cada 1 hora
// Anti-spam: mínimo 10 min entre alertas Telegram para evitar notificaciones repetidas
const unsigned long MIN_ENTRE_ALERTAS = 600000;

// ── ZONA HORARIA ───────────────────────────────────────────
// Chile Continental (UTC-3 en verano / UTC-4 en invierno)
// Ajusta el offset según la época del año
const long UTC_OFFSET_SEGUNDOS = -3 * 3600; // UTC-3

// ── ESTADO GLOBAL ──────────────────────────────────────────
bool   estadoAnterior        = true;   // true=húmedo al inicio (evita falsa alerta al arrancar)
float  lluviaProxima24h      = 0.0;   // mm de lluvia proyectados próximas 24h
String diasRecomendadosRiego = "";    // Texto con días sin lluvia → buenos para regar
String climaDescripcion      = "";    // Descripción del clima actual (ej. "Cielo despejado")
float  tempActual            = 0.0;   // Temperatura actual en °C

unsigned long ultimaLecturaSensor = 0;
unsigned long ultimaConsultaClima = 0;
unsigned long ultimaAlertaTelegram = 0;

// ── CLIENTES DE RED ────────────────────────────────────────
WiFiClient        clienteHTTP;       // Para ThingSpeak (HTTP)
WiFiClientSecure  clienteSeguro;     // Para Telegram (HTTPS)

// Bot de Telegram
UniversalTelegramBot bot(TELEGRAM_TOKEN, clienteSeguro);

// Cliente NTP para obtener hora real
WiFiUDP ntpUDP;
NTPClient timeClient(ntpUDP, "pool.ntp.org", UTC_OFFSET_SEGUNDOS, 60000);

// ============================================================
//  SETUP
// ============================================================
void setup() {
  Serial.begin(115200);
  delay(100);

  pinMode(PIN_LED, OUTPUT);
  digitalWrite(PIN_LED, LOW);

  // ESP8266 requiere deshabilitar verificación SSL para Telegram
  // (limitación de memoria del chip; aceptable en contexto académico)
  clienteSeguro.setInsecure();

  Serial.println("\n╔══════════════════════════════╗");
  Serial.println("║  SISTEMA DE RIEGO INTELIGENTE  ║");
  Serial.println("╚══════════════════════════════╝");

  conectarWiFi();
  ThingSpeak.begin(clienteHTTP);

  // Iniciar cliente de hora
  timeClient.begin();
  timeClient.update();

  // Consultar clima al arrancar
  consultarClima();

  Serial.println("[SISTEMA] Listo. Umbral de riego: " + String(UMBRAL_RIEGO) + "%");
  Serial.println("[SISTEMA] Monitoreando cada " + String(INTERVALO_SENSOR / 1000) + " segundos");
}

// ============================================================
//  LOOP PRINCIPAL
// ============================================================
void loop() {
  unsigned long ahora = millis();

  // ── 1. Leer sensor y procesar ───────────────────────────
  if (ahora - ultimaLecturaSensor >= INTERVALO_SENSOR) {
    ultimaLecturaSensor = ahora;
    timeClient.update();

    int   rawADC  = analogRead(PIN_SENSOR);
    float humedad = calcularHumedad(rawADC);
    bool  esSeco  = (humedad < UMBRAL_RIEGO);

    // Actualizar LED: encendido = seco, apagado = húmedo
    digitalWrite(PIN_LED, esSeco ? HIGH : LOW);

    // Log en Serial Monitor
    Serial.println("──────────────────────────────────");
    Serial.println("[SENSOR] ADC      : " + String(rawADC));
    Serial.println("[SENSOR] Humedad  : " + String(humedad, 1) + "%");
    Serial.println("[SENSOR] Estado   : " + String(esSeco ? "SECO ⚠️" : "HÚMEDO ✅"));
    Serial.println("[HORA]   " + obtenerHoraFormateada());

    // Enviar datos a ThingSpeak siempre (para historial continuo)
    enviarAThingSpeak(humedad, esSeco ? 0 : 1, lluviaProxima24h);

    // ── Detectar cambio de estado húmedo → seco ──────────
    bool alertaPermitida = (ahora - ultimaAlertaTelegram >= MIN_ENTRE_ALERTAS);

    if (esSeco && !estadoAnterior && alertaPermitida) {
      // Suelo acaba de secarse → enviar alerta al jardinero
      enviarAlertaTelegram(humedad, rawADC);
      ultimaAlertaTelegram = ahora;
    } else if (esSeco && estadoAnterior && alertaPermitida) {
      // Suelo sigue seco pero aún no se ha regado → recordatorio cada 10 min
      enviarRecordatorioTelegram(humedad);
      ultimaAlertaTelegram = ahora;
    } else if (!esSeco && estadoAnterior) {
      // Suelo pasó de seco a húmedo → confirmar al jardinero
      enviarConfirmacionRiego(humedad);
    }

    estadoAnterior = esSeco;
  }

  // ── 2. Actualizar pronóstico del clima (cada hora) ──────
  if (ahora - ultimaConsultaClima >= INTERVALO_CLIMA || ultimaConsultaClima == 0) {
    ultimaConsultaClima = ahora;
    consultarClima();
  }
}

// ============================================================
//  FUNCIONES DE TELEGRAM
// ============================================================

/**
 * enviarAlertaTelegram(humedad, rawADC)
 * Mensaje principal cuando el suelo detecta por primera vez que está seco.
 * Incluye: humedad, hora, clima, pronóstico y link al dashboard.
 */
void enviarAlertaTelegram(float humedad, int rawADC) {
  Serial.println("[Telegram] Enviando alerta de suelo seco...");

  String mensaje = "🌱 *ALERTA DE RIEGO*\n";
  mensaje += "──────────────────\n";
  mensaje += "⚠️ El suelo está *SECO* y necesita agua\n\n";

  mensaje += "📊 *Estado del suelo:*\n";
  mensaje += "   💧 Humedad actual: *" + String(humedad, 1) + "%*\n";
  mensaje += "   📉 Umbral de riego: " + String(UMBRAL_RIEGO) + "%\n";
  mensaje += "   🔢 Lectura sensor (ADC): " + String(rawADC) + "\n\n";

  mensaje += "🕐 *Hora de detección:*\n";
  mensaje += "   " + obtenerHoraFormateada() + "\n\n";

  mensaje += "🌤 *Clima actual (" + String(OWM_CITY) + "):*\n";
  if (climaDescripcion.length() > 0) {
    mensaje += "   " + climaDescripcion + " — " + String(tempActual, 1) + "°C\n";
    mensaje += "   🌧 Lluvia próximas 24h: *" + String(lluviaProxima24h, 1) + " mm*\n\n";
  } else {
    mensaje += "   (sin datos de clima disponibles)\n\n";
  }

  // Recomendación inteligente basada en lluvia esperada
  mensaje += "💡 *Recomendación:*\n";
  if (lluviaProxima24h >= 5.0) {
    mensaje += "   ⏳ Esperar — lluvia prevista de " + String(lluviaProxima24h, 1) + " mm en 24h\n";
    mensaje += "   Puedes postergar el riego.\n\n";
  } else if (lluviaProxima24h > 0 && lluviaProxima24h < 5.0) {
    mensaje += "   🤔 Lluvia leve prevista (" + String(lluviaProxima24h, 1) + " mm)\n";
    mensaje += "   Insuficiente — se recomienda regar igualmente.\n\n";
  } else {
    mensaje += "   ✅ Regar lo antes posible — sin lluvia prevista.\n\n";
  }

  // Días buenos para regar (sin lluvia) en los próximos 5 días
  if (diasRecomendadosRiego.length() > 0) {
    mensaje += "📅 *Mejores días para regar (próx. 5 días):*\n";
    mensaje += "   " + diasRecomendadosRiego + "\n\n";
  }

  mensaje += "📈 *Ver historial de humedad:*\n";
  mensaje += "   [Dashboard ThingSpeak](" + String(TS_CANAL_URL) + ")\n";
  mensaje += "──────────────────";

  bool enviado = bot.sendMessage(TELEGRAM_CHAT_ID, mensaje, "Markdown");

  if (enviado) {
    Serial.println("[Telegram] ✅ Alerta enviada correctamente");
  } else {
    Serial.println("[Telegram] ❌ Error al enviar alerta");
  }
}

/**
 * enviarRecordatorioTelegram(humedad)
 * Recordatorio periódico si el suelo sigue seco después del primer aviso.
 */
void enviarRecordatorioTelegram(float humedad) {
  Serial.println("[Telegram] Enviando recordatorio...");

  String mensaje = "🔁 *RECORDATORIO — Suelo aún seco*\n";
  mensaje += "──────────────────\n";
  mensaje += "💧 Humedad: *" + String(humedad, 1) + "%* (bajo umbral de " + String(UMBRAL_RIEGO) + "%)\n";
  mensaje += "🕐 Hora: " + obtenerHoraFormateada() + "\n";

  if (lluviaProxima24h >= 5.0) {
    mensaje += "⏳ Lluvia prevista: " + String(lluviaProxima24h, 1) + " mm en 24h\n";
  } else {
    mensaje += "⚠️ Sin lluvia prevista — regar a la brevedad.\n";
  }

  mensaje += "\n📈 [Ver historial](" + String(TS_CANAL_URL) + ")";

  bot.sendMessage(TELEGRAM_CHAT_ID, mensaje, "Markdown");
}

/**
 * enviarConfirmacionRiego(humedad)
 * Mensaje de confirmación cuando el suelo vuelve a estar húmedo.
 */
void enviarConfirmacionRiego(float humedad) {
  Serial.println("[Telegram] Enviando confirmación de riego...");

  String mensaje = "✅ *Suelo hidratado correctamente*\n";
  mensaje += "──────────────────\n";
  mensaje += "💧 Humedad actual: *" + String(humedad, 1) + "%*\n";
  mensaje += "🕐 Hora: " + obtenerHoraFormateada() + "\n";
  mensaje += "👍 El suelo ya no necesita riego.\n\n";
  mensaje += "📈 [Ver historial](" + String(TS_CANAL_URL) + ")";

  bot.sendMessage(TELEGRAM_CHAT_ID, mensaje, "Markdown");
}

// ============================================================
//  FUNCIONES DE SENSOR Y DATOS
// ============================================================

/**
 * calcularHumedad(rawADC)
 * Convierte el valor ADC del sensor a porcentaje de humedad (0–100%).
 * Usa interpolación lineal entre los valores de calibración.
 * El sensor capacitivo V1.2 entrega MAYOR voltaje cuando está SECO
 * y MENOR voltaje cuando está HÚMEDO (lógica inversa al resistivo).
 */
float calcularHumedad(int rawADC) {
  rawADC = constrain(rawADC, SENSOR_AGUA, SENSOR_SECO);
  // SECO (valor alto) → 0% | HÚMEDO (valor bajo) → 100%
  float humedad = (float)(SENSOR_SECO - rawADC) / (float)(SENSOR_SECO - SENSOR_AGUA) * 100.0;
  return constrain(humedad, 0.0, 100.0);
}

/**
 * enviarAThingSpeak(humedad, estado, lluvia)
 * Sube los 3 campos al canal ThingSpeak para dashboard e historial.
 * Límite plan gratuito: mínimo 15 segundos entre envíos.
 */
void enviarAThingSpeak(float humedad, int estado, float lluvia) {
  ThingSpeak.setField(1, humedad);  // % de humedad del suelo
  ThingSpeak.setField(2, estado);   // 0 = seco / 1 = húmedo
  ThingSpeak.setField(3, lluvia);   // mm de lluvia proyectados 24h

  int resultado = ThingSpeak.writeFields(TS_CHANNEL_ID, TS_WRITE_KEY);

  if (resultado == 200) {
    Serial.println("[ThingSpeak] ✅ Datos enviados");
  } else {
    Serial.println("[ThingSpeak] ❌ Error. Código: " + String(resultado));
  }
}

// ============================================================
//  FUNCIÓN DE CLIMA
// ============================================================

/**
 * consultarClima()
 * Consulta el pronóstico de 5 días (intervalos de 3h) de OpenWeatherMap.
 * Actualiza: lluviaProxima24h, diasRecomendadosRiego, climaDescripcion, tempActual.
 */
void consultarClima() {
  if (WiFi.status() != WL_CONNECTED) {
    Serial.println("[Clima] Sin WiFi, omitiendo consulta");
    return;
  }

  Serial.println("[Clima] Consultando pronóstico...");

  // Endpoint gratuito: forecast cada 3 horas, 5 días (40 intervalos)
  String url = "http://api.openweathermap.org/data/2.5/forecast?"
               "q=" + String(OWM_CITY) + "," + String(OWM_COUNTRY) +
               "&appid=" + String(OWM_API_KEY) +
               "&units=metric"
               "&lang=es"     // Descripciones en español
               "&cnt=40";

  HTTPClient http;
  http.begin(clienteHTTP, url);
  int httpCode = http.GET();

  if (httpCode != 200) {
    Serial.println("[Clima] ❌ Error HTTP: " + String(httpCode));
    http.end();
    return;
  }

  String payload = http.getString();
  http.end();

  // Parsear JSON — 6KB suficiente para los campos relevantes del forecast
  DynamicJsonDocument doc(6144);
  DeserializationError error = deserializeJson(doc, payload);

  if (error) {
    Serial.println("[Clima] ❌ Error JSON: " + String(error.c_str()));
    return;
  }

  // ── Clima actual (primer intervalo) ─────────────────────
  tempActual       = doc["list"][0]["main"]["temp"].as<float>();
  climaDescripcion = doc["list"][0]["weather"][0]["description"].as<String>();
  // Capitalizar primera letra
  if (climaDescripcion.length() > 0) {
    climaDescripcion[0] = toupper(climaDescripcion[0]);
  }

  // ── Lluvia próximas 24h (8 intervalos × 3h = 24h) ──────
  lluviaProxima24h = 0.0;
  for (int i = 0; i < 8 && i < (int)doc["list"].size(); i++) {
    if (doc["list"][i].containsKey("rain") &&
        doc["list"][i]["rain"].containsKey("3h")) {
      lluviaProxima24h += doc["list"][i]["rain"]["3h"].as<float>();
    }
  }

  // ── Días recomendados para regar (sin lluvia significativa) ─
  // Un día es candidato si la lluvia total del día < 3mm
  diasRecomendadosRiego = "";
  String diasSemana[] = {"Dom", "Lun", "Mar", "Mié", "Jue", "Vie", "Sáb"};

  String fechaActual = "";
  float  lluviaDia   = 0.0;
  float  tempMaxDia  = 0.0;

  for (int i = 0; i < (int)doc["list"].size(); i++) {
    String dtTxt = doc["list"][i]["dt_txt"].as<String>();
    String fecha = dtTxt.substring(0, 10); // "YYYY-MM-DD"
    float  temp  = doc["list"][i]["main"]["temp"].as<float>();

    float lluviaItem = 0.0;
    if (doc["list"][i].containsKey("rain") &&
        doc["list"][i]["rain"].containsKey("3h")) {
      lluviaItem = doc["list"][i]["rain"]["3h"].as<float>();
    }

    if (fecha != fechaActual && fechaActual.length() > 0) {
      if (lluviaDia < 3.0) {
        // Obtener día de la semana a partir del timestamp Unix
        long ts     = doc["list"][i - 1]["dt"].as<long>();
        int  diaSem = ((ts / 86400L) + 4) % 7;
        diasRecomendadosRiego += diasSemana[diaSem];
        diasRecomendadosRiego += " (" + String((int)round(tempMaxDia)) + "°C)  ";
      }
      lluviaDia  = 0.0;
      tempMaxDia = 0.0;
    }

    fechaActual = fecha;
    lluviaDia  += lluviaItem;
    if (temp > tempMaxDia) tempMaxDia = temp;
  }

  Serial.println("[Clima] ✅ " + climaDescripcion + " — " + String(tempActual, 1) + "°C");
  Serial.println("[Clima] Lluvia 24h : " + String(lluviaProxima24h, 1) + " mm");
  Serial.println("[Clima] Días riego : " + (diasRecomendadosRiego.length() > 0 ? diasRecomendadosRiego : "ninguno (lluvia todos los días)"));
}

// ============================================================
//  UTILIDADES
// ============================================================

/**
 * conectarWiFi()
 * Conecta al WiFi con hasta 30 reintentos y reinicia si falla.
 */
void conectarWiFi() {
  Serial.print("[WiFi] Conectando a " + String(WIFI_SSID));
  WiFi.mode(WIFI_STA);
  WiFi.begin(WIFI_SSID, WIFI_PASSWORD);

  int intentos = 0;
  while (WiFi.status() != WL_CONNECTED && intentos < 30) {
    delay(500);
    Serial.print(".");
    intentos++;
  }

  if (WiFi.status() == WL_CONNECTED) {
    Serial.println("\n[WiFi] Conectado — IP: " + WiFi.localIP().toString());
    Serial.println("[WiFi] RSSI: " + String(WiFi.RSSI()) + " dBm");
  } else {
    Serial.println("\n[WiFi] ERROR: No se pudo conectar. Reiniciando...");
    ESP.restart();
  }
}

/**
 * obtenerHoraFormateada()
 * Retorna la hora actual como string "HH:MM:SS — DD/MM/YYYY".
 * Usa NTP para sincronizar con servidores de tiempo reales.
 */
String obtenerHoraFormateada() {
  time_t tiempoEpoch = timeClient.getEpochTime();
  struct tm* tiempoInfo = localtime(&tiempoEpoch);

  char buffer[30];
  strftime(buffer, sizeof(buffer), "%H:%M:%S — %d/%m/%Y", tiempoInfo);
  return String(buffer);
}

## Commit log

2026-06-24 Modelos 3D del prototipo final
    [CajaSinTapa.f3d, EstacaFinal.f3d, TapaPanelSolar.f3d]
2026-06-24 Primer codigo que usamos
    Este codigo era usando la supuesta luz rgb que iba a servir de indicador, se sacó
2026-06-25 Actualizar FUENTES.md con librerías y adaptaciones
    Se actualizó el archivo FUENTES.md para incluir librerías utilizadas, adaptaciones de código, y hardware empleado en el proyecto.
2026-06-25 Remove LED indicator note from README
    Removed a note about the LED indicator for system operation.
2026-07-10 Gemelo 3D final
    [Gemelo 3D.f3z]
